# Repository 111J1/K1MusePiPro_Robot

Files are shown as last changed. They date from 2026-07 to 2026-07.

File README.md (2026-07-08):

# K1MUSE — 全链路本地具身智能服务机器人


[]()

> [!WARNING]
> ## ⚠️ 重要声明
>
> 本仓库是对真实部署代码的**重构版本**，用于展示**核心算法和系统架构设计**。
>
> **本仓库不能直接部署运行**，原因包括但不限于：
> - 缺少运行时依赖：SpacemiT AI SDK、sherpa-onnx 模型文件、ROS2 系统镜像、Orbbec 相机 SDK 等
> - 部分文件路径、IP 地址、网络配置已从真实部署环境中抽象化
> - 硬件相关文件（设备树、udev 规则、systemd 服务、SSH 密钥路径等）需根据实际硬件调整
> - AI 模型权重文件（唤醒词、ASR、YOLO、TTS 等）未包含在本仓库中
>
> 本仓库仅供**学习、参考和研究**使用。

---

## 项目简介

K1MUSE 是一台基于**进迭时空 K1 (SpacemiT K1) RISC-V 处理器**的全链路本地具身智能服务机器人。所有 AI 推理（语音识别、视觉检测、大语言模型、语音合成）均在边缘端完成，无需云端依赖。

**核心能力：** 语音交互 → 视觉感知 → LLM 理解 → 自主导航 → 机械臂操作

**硬件平台：**
- **主控**: SpacemiT K1 Muse Pi Pro (RISC-V 64-bit, ~2 TOPS NPU)
- **协处理**: STM32G474 (Cortex-M4F, 实时电机控制)
- **传感器**: LD06 激光雷达, YB IMU, Orbbec 深度相机
- **执行器**: 4 轮麦克纳姆底盘 + 可升降 6-DOF 机械臂 + 电动夹爪

## 系统架构

```mermaid
graph TB
    subgraph "Android 手机"
        APP[RobotController<br/>蓝牙遥控 / 地图 / 导航]
    end

    subgraph "K1 MusePi Pro - ROS2 Humble"
        AI[语音链路<br/>唤醒词→VAD→ASR→意图→TTS]
        VISION[视觉检测<br/>YOLO + 3D 定位]
        LLM[本地 LLM<br/>llama.cpp HTTP API]
        SUPERVISOR[多模态监督器<br/>8 状态交互 FSM]
        SLAM[SLAM 导航<br/>Cartographer + Nav2]
        BRIDGE_MCU[MCU 串口桥<br/>UART 帧协议]
        BRIDGE_BT[蓝牙 App 桥<br/>K1MB 协议]
        CONTROL[上层控制<br/>取放任务规划]
    end

    subgraph "STM32G474 - FreeRTOS"
        CHASSIS[4 轮麦克纳姆底盘<br/>PID 速度控制]
        ARM[SO101 5-DOF 机械臂<br/>IK 运动学]
        LIFT[升降机构<br/>PID 位置控制]
    end

    APP <--"蓝牙 RFCOMM<br/>(K1MB 协议)"--> BRIDGE_BT
    BRIDGE_BT --> SUPERVISOR
    AI --> SUPERVISOR
    VISION --> SUPERVISOR
    LLM --> AI
    SUPERVISOR --> CONTROL
    CONTROL --> BRIDGE_MCU
    SLAM --> BRIDGE_MCU
    BRIDGE_MCU <--"UART<br/>(0xA5 0x5A 帧)"--> CHASSIS
    BRIDGE_MCU <--"UART"--> ARM
    BRIDGE_MCU <--"UART"--> LIFT
```

## 仓库结构

```
k1muse/
├── firmware/          STM32G474 FreeRTOS 固件（底盘/机械臂/升降台）
├── ros2/              所有 ROS2 包
│   ├── navigation/    导航与通信（SLAM, MCU 桥, 蓝牙桥, LiDAR, IMU）
│   ├── ai/            AI 运行时（语音/视觉/LLM/多模态监督器）
│   └── control/       上层控制（取放任务, 抓取配置, STM32 串口客户端）
├── android/           Android 蓝牙遥控器（Kotlin/Jetpack Compose）
├── hardware/          硬件设计（3D CAD, PCB, MATLAB 运动学, URDF）
├── docs/              集中文档（架构, 协议, 快速入门）
└── tools/             开发工具脚本
```

## 快速导航

| 我想... | 查看 |
|---|---|
| 了解底盘控制算法 | [`firmware/Application/Module/mdl_chassis.c`](firmware/Application/Module/mdl_chassis.c) |
| 了解机械臂 IK 运动学 | [`firmware/Application/Module/SO101ARM/so101_algorithm.c`](firmware/Application/Module/SO101ARM/so101_algorithm.c) |
| 了解 AI 运行时架构 | [`ros2/ai/k1muse_ai_runtime/`](ros2/ai/k1muse_ai_runtime/) |
| 了解多模态交互 FSM | [`ros2/ai/k1muse_multimodal_supervisor/`](ros2/ai/k1muse_multimodal_supervisor/) |
| 了解语音意图路由 | [`ros2/ai/k1muse_voice_intent/`](ros2/ai/k1muse_voice_intent/) |
| 了解取放任务规划 | [`ros2/control/k1muse_control_core/`](ros2/control/k1muse_control_core/) |
| 了解通信协议 | [`docs/protocol.md`](docs/protocol.md) |
| 了解 Android App | [`android/`](android/) |
| 了解机械结构 | [`hardware/cad/`](hardware/cad/) |
| 了解 PCB 设计 | [`hardware/pcb/`](hardware/pcb/) |

## 关键技术指标

| 指标 | 数值 |
|---|---|
| AI 推理延迟（语音→意图） | < 2s（全本地） |
| SLAM 建图精度 | 0.05m 分辨率 |
| 机械臂重复定位精度 | ±1.5cm |
| 底盘最大速度 | 1.4 m/s |
| 升降行程 | 0.5m |
| 机械臂工作半径 | 0.5m |
| 蓝牙地图传输 | zlib 压缩分块, 最大 4MiB |

## 许可

- **软件代码** (`firmware/`, `ros2/`, `android/`, `tools/`): [Apache License 2.0](LICENSE)
- **硬件设计** (`hardware/`): [CC-BY-SA 4.0](hardware/README.md)
- **文档** (`docs/`): [CC-BY 4.0](docs/)

第三方代码（STM32 HAL, FreeRTOS, CMSIS, LDROBOT 激光雷达驱动等）保留其原始许可。

## 相关链接

- 进迭时空 K1: https://www.spacemit.com
- ROS2 Humble: https://docs.ros.org/en/humble/
- Cartographer: https://google-cartographer-ros.readthedocs.io/
- Nav2: https://navigation.ros.org/
- sherpa-onnx: https://github.com/k2-fsa/sherpa-onnx

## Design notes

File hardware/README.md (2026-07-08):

# 硬件设计文件

> [!WARNING]
> ## ⚠️ 重要声明
> 本目录包含的是设计参考文件，不构成可直接生产的完整制造包。
> 详见[仓库根目录 README](../README.md)。

## 许可

**CC-BY-SA 4.0** — 署名-相同方式共享 4.0 国际

您可以自由地：
- 分享 — 在任何媒介以任何形式复制、发行本作品
- 改编 — 修改、转换或以本作品为基础进行创作

惟须遵守下列条件：
- 署名 — 必须给出适当的署名
- 相同方式共享 — 如果您再混合、转换或者基于本作品进行创作，您必须基于与原先许可协议相同的许可协议分发您贡献的作品

完整许可文本: https://creativecommons.org/licenses/by-sa/4.0/legalcode.zh-hans

## 目录结构

```
hardware/
├── cad/         3D CAD 文件 (.step, .stl, .3mf)
│   ├── chassis/    底盘部件（麦克纳姆轮安装、电池支架等）
│   ├── arm/        SO101 5-DOF 机械臂零件
│   ├── lift/       升降机构（多层平台）
│   └── mounts/     传感器安装座（LiDAR、相机、红外等）
├── pcb/         PCB 设计文件（立创 EDA 格式）
│   ├── motor-driver/   电机驱动板
│   ├── stm32-core/     STM32G474 核心板
│   └── baseboard/      泰山派扩展底板
├── matlab/      MATLAB 运动学分析脚本
│   └── assets/         可视化用 STL 模型
└── urdf/        URDF 机器人描述文件
```

## 软件

- 3D CAD: Fusion 360 / SolidWorks (推荐)
- PCB: 立创 EDA
- MATLAB: R2023a+

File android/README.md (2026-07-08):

# Android 蓝牙控制器 App

> [!WARNING]
> ## ⚠️ 重要声明
> 本模块是对真实部署代码的重构版本，用于展示核心算法和系统架构。**不能直接部署运行。**
> 详见[仓库根目录 README](../README.md)。

## 概述

基于 Kotlin + Jetpack Compose 的 Android 机器人遥控器，通过经典蓝牙 (RFCOMM/SPP) 与机器人通信。

## 双模式

- **Direct SPP 模式**: 通过 HC-05 蓝牙模块直接控制 STM32 底盘 (只写)
- **K1 Map/Nav 模式**: 连接 K1 上位机，实时查看 SLAM 地图、机器人位姿、导航路径 (双向 K1MB 协议)

## 技术栈

| 项目 | 版本/值 |
|---|---|
| Kotlin | 2.2.10 |
| Compose BOM | 2026.02.01 |
| AGP | 9.2.1 |
| Min SDK | 28 |
| Target SDK | 36 |
| 包名 | com.embodiedai.robotcontroller |

## 关键特性

- 自定义 K1MB 二进制协议（17 种消息类型，最大 4 MiB 载荷）
- zlib 压缩地图分块渲染（ByteArray 环形缓冲区，避免 GC 卡顿）
- 4 种蓝牙连接 fallback 策略
- 监督器自动探测 → 启动 bridge → 5 次自动重连
- 地图多边形区域标注（最近自由栅格中心计算）
- 拖拽平移、双指缩放 (0.25x-16x)、0/90/180/270 度旋转

## 核心文件

| 文件 | 功能 |
|---|---|
| `K1MapModeScreen.kt` | 地图/Nav 主界面 (~3900 行) |
| `K1MobileProtocol.kt` | K1MB 协议编解码 + 帧解析器 |
| `ControlProtocol.kt` | STM32 Direct SPP 帧编码 |
| `K1MapBluetoothClient.kt` | 蓝牙连接 + 遥操线程 |
| `RegionModels.kt` | 地图区域数据模型 |

## 许可

Apache License 2.0

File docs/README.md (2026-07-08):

# 项目文档

## 文档索引

| 文档 | 内容 |
|---|---|
| `architecture.md` | 完整系统架构说明 |
| `protocol.md` | K1↔STM32 和 K1↔App 通信协议规范 |
| `INTERFACE.md` | 外部接口规范（原 MusePiPro_prj） |
| `ENV_DEV.md` | 部署环境恢复手册 |
| `SPECS.md` | 系统规格说明 |
| `CURRENT_RUNTIMEFLOW.md` | AI 运行时数据流 |
| `control_manager_api_contract.md` | 控制管理器 API 约定 |
| `control_manager_engineering_architecture.md` | 控制管理器工程架构 |
| `coordinate_frames_and_lift_z.md` | 坐标系与升降 Z 说明 |

## 许可

文档内容以 [CC-BY 4.0](https://creativecommons.org/licenses/by/4.0/) 许可发布。

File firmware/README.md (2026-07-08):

# STM32G474 固件 — 实时控制层

> [!WARNING]
> ## ⚠️ 重要声明
> 本模块是对真实部署代码的重构版本，用于展示核心算法和系统架构。**不能直接部署运行。**
> 详见[仓库根目录 README](../README.md)。

## 概述

基于 STM32G474VCT6 (Cortex-M4F, 144MHz) 的实时控制固件，运行 FreeRTOS V10.3.1。

## 架构

```
Application/
├── Algorithm/      CRC8, PID 控制器
├── Device/         硬件抽象层（电机、舵机、传感器、OLED）
├── Driver/         寄存器级驱动（HRTIM, UART DMA, ADC, I2C, DWT）
├── Module/         业务逻辑层
│   ├── SO101ARM/   SO101 5-DOF 机械臂 + 逆运动学
│   ├── mdl_chassis   麦克纳姆底盘运动学
│   ├── mdl_lift      升降机构 PID 控制
│   ├── mdl_control_protocol   二进制帧协议解析
│   └── mdl_control_arbitration  控制权仲裁
└── Task/           FreeRTOS 8 个任务入口
```

## FreeRTOS 任务拓扑

| 任务 | 优先级 | 周期 | 功能 |
|---|---|---|---|
| CommandTask | High (24) | 10ms | UART 帧解析与分发 |
| ChassisTask | AboveNormal (22) | 10ms | 底盘运动控制 |
| ArmTask | AboveNormal (22) | 10ms | 机械臂状态机 |
| LiftTask | AboveNormal (22) | 10ms | 升降台 PID + 归零 |
| TelemetryTask | Normal (20) | 事件驱动 | 遥测编码与发送 |
| PeripheralTask | Normal (20) | 周期 | 传感器轮询 |
| DemoTask | Normal (20) | 10ms | 演示序列编排 |
| OledTask | Low (18) | 100ms | OLED 显示 |

## 通信协议

与上位机 (K1) 通过 UART 通信，二进制帧格式：
`0xA5 0x5A SRC TARGET CMD SEQ LEN PAYLOAD(0-64) CRC8`

详见 [`docs/protocol.md`](../docs/protocol.md)。

## 关键算法

- **机械臂 IK**: 螺旋转轴 (PoE) 表示，位置用阻尼最小二乘法 (LM)，姿态用闭式解析解
- **底盘**: 麦克纳姆轮逆运动学 (4 轮)，1/√2 缩放，330 RPM 饱和保护
- **升降台**: P-only PID (Kp=7.0)，霍尔传感器归零 + 运行时参考修正

## 构建

- IDE: Keil MDK-ARM (Arm Compiler 6)
- STM32CubeMX 配置文件: `EmbodiedAI_Robot.ioc`

## 许可

Apache License 2.0

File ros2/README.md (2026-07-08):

# ROS2 包 — 上层计算层

> [!WARNING]
> ## ⚠️ 重要声明
> 本模块是对真实部署代码的重构版本，用于展示核心算法和系统架构。**不能直接部署运行。**
> 详见[仓库根目录 README](../README.md)。

## 概述

基于 ROS2 Humble 的上层计算软件栈，运行在 SpacemiT K1 MusePi Pro 上。分为三个子系统：

| 子系统 | 目录 | 功能 |
|---|---|---|
| 导航与通信 | [`navigation/`](navigation/) | SLAM 建图、路径规划、传感器驱动、通信桥 |
| AI 运行时 | [`ai/`](ai/) | 语音交互、视觉检测、LLM、多模态监督器 |
| 上层控制 | [`control/`](control/) | 取放任务规划、抓取配置、串口客户端 |

## 依赖关系

```
navigation/  ← 独立构建（LiDAR/IMU 驱动 + Cartographer + Nav2）
ai/          ← 依赖 control/（需先 source control 的 install）
control/     ← 独立构建（纯算法，无硬件依赖）
```

构建顺序：
```bash
# 1. 先构建 control
cd control/
colcon build

# 2. 再构建 ai（依赖 manager_msgs）
cd ai/
source ../control/install/setup.bash
colcon build

# 3. navigation 可以独立构建（但需要 LiDAR/IMU 硬件或 mock）
cd navigation/
colcon build
```

## 许可

Apache License 2.0

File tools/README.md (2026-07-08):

# 开发工具

> [!WARNING]
> ## ⚠️ 重要声明
> 本目录中的工具脚本是对真实部署版本的抽象。**可能需要根据实际环境调整路径和端口配置。**

## 工具列表

| 工具 | 功能 |
|---|---|
| `mcu_sim.py` | STM32 MCU 模拟器（通过 CH340 USB-UART），发送 ChassisStatus 帧并打印收到的命令 |
| `test_comms.py` | 通信测试脚本 |
| `full_chain_test.sh` | 全链路集成测试 |
| `demo_console.py` | 演示控制台（通过蓝牙发送演示命令） |
| `demo_tuning_profile.json` | 演示调试参数 |
| `bluetooth_pairing_agent.py` | BlueZ 自动配对代理 |

## 许可

Apache License 2.0

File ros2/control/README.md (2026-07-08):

# 上层控制子系统

> [!WARNING]
> ## ⚠️ 重要声明
> 本模块是对真实部署代码的重构版本。**不能直接部署。** 详见[仓库根目录 README](../../README.md)。

## 包含的 ROS2 包

| 包 | 语言 | 功能 |
|----|---|---|
| `k1muse_control_core` | C11 | 纯 C 库：串行帧协议、取放状态机 (22 状态)、放置规划器、抓取配置验证 |
| `k1muse_control_manager` | C++17 | ROS2 动作服务器：任务执行、抓取执行器、设备就绪管理、STM32 串口客户端 |
| `k1muse_task_manager` | C++17 | ROS2 节点：语音意图 → ExecuteTask 动作路由 |
| `k1muse_manager_msgs` | ROS2 IDL | 任务/动作消息定义 (ExecuteTask.action, TaskStatus.msg) |

## 取放任务流程

```
语音意图 → TaskManager → ExecuteTask Action → ControlManager
    → GraspTaskExecutor
        → stop_all()
        → ensure_arm_ready() / ensure_lift_ready()  [回零优化]
        → lift_move_z() → arm_gripper(open)
        → move_pose(pregrasp) → move_pose(grasp)
        → arm_gripper(close) → settle → carry
```

## 放置规划器

输入：目标在底盘坐标系中的 3D 位置 + 抓取配置
输出：底盘移动距离/方向、升降台 Z 目标、4 个手臂姿态 (grasp/pregrasp/lifted/retreat)

## 抓取配置

预标定 3 个物体 4 种抓取方式：
- bottle.side, box.side, box.top, umbrella.top

## Demo-Tolerant 模式

- 手臂姿态容差：±1.5cm
- 夹持器：无故障即假定成功
- 升降台：严格检查 ±2cm

## 许可

Apache License 2.0

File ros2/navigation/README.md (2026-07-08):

# 导航与通信子系统

> [!WARNING]
> ## ⚠️ 重要声明
> 本模块是对真实部署代码的重构版本。**不能直接部署。** 详见[仓库根目录 README](../../README.md)。

## 包含的 ROS2 包

| 包 | 语言 | 功能 |
|----|---|---|
| `k1muse_mcu_bridge` | C++17 | STM32 串口桥接节点（UART 帧协议、里程计发布、cmd_vel 路由） |
| `k1muse_mobile_bridge` | C++17 + Python | 蓝牙 App 桥接（K1MB 协议、地图分块/zlib、位姿发布） |
| `k1muse_slam_nav` | Python/Launch | Cartographer SLAM + Nav2 导航编排 |
| `k1muse_description` | URDF/Xacro | 机器人模型（X-omni 底盘 + SO101 机械臂） |
| `ldlidar_stl_ros2` | C++14 | LD06 激光雷达驱动 |
| `imu_ros2_device` | Python | YB IMU 驱动 |
| `k1muse_exploration` | Python | RRT/Frontier 自主探索 |

## 硬件接口

| 设备 | 端口 | 波特率 |
|---|---|---|
| STM32 MCU | /dev/mymcu (UART4) | 115200 |
| LD06 LiDAR | /dev/mylidar (UART5) | 230400 |
| YB IMU | /dev/myimu (CH340 USB) | 115200 |
| 蓝牙 | /dev/rfcomm0 | — |

## 分布式部署

支持 MUSE Pi Pro + Raspberry Pi 4B 双机 ROS2 通信：
- MUSE: 传感器驱动 + 通信桥（实时 I/O）
- RPi4: Cartographer + Nav2 + 探索（计算密集型）
- 通信: 有线以太网 CycloneDDS, ROS_DOMAIN_ID=42

## 许可

Apache License 2.0

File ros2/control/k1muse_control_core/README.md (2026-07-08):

# k1muse_control_core 纯C控制核心

`k1muse_control_core` 是一套与操作系统和ROS2解耦的纯C控制核心，同时服务于：

- PC阶段：由Python脚本暂时替代K1主控板，通过USB-UART控制真实STM32。
- K1阶段：由ROS2 C++节点直接链接本C库，复用协议、规划和任务状态机。

本库不包含Python、ROS2、串口设备名、线程或操作系统相关代码。因此从PC迁移到K1时，只需替换外层通信和ROS2接口，不需要重写核心控制流程。

## 分层结构

本库参考STM32下位机的分层方式组织：

| 层级 | 目录 | 职责 |
|---|---|---|
| Algorithm | `src/algorithm` | CRC8及通用数学算法 |
| Protocol | `src/protocol` | 字节流帧编码、解析、粘包和拆包处理 |
| Device | `src/device` | STM32命令构造，以及STATUS/RESULT解析 |
| Module | `src/module` | 抓取配置校验、底盘和升降布置计算 |
| Task | `src/task` | 抓取、携带、运输和放置状态机 |

平台外壳只需提供：

- 当前时间。
- 收到的串口字节。
- 配置数据。
- 命令完成、失败、超时或取消事件。
- 将C核心输出的动作发送给STM32。

PC平台外壳位于 `tools/pc_controller`；最终K1平台外壳将由ROS2 C++节点实现。

## 协议层

协议层实现STM32当前使用的帧格式：

```text
SOF1 SOF2 SRC TARGET CMD SEQ LEN PAYLOAD CRC8
```

当前目标编号以STM32源码为准：

```text
SYSTEM  = 0x00
CHASSIS = 0x01
ARM     = 0x02
LIFT    = 0x03
```

协议层支持：

- CRC-8/ATM。
- 最大64字节载荷。
- 小端整数和IEEE754浮点数。
- 半帧、连续多帧和错误CRC处理。
- ARM和LIFT命令RESULT解析。
- CHASSIS、ARM和LIFT周期STATUS解析。

协议常量应始终以STM32工程中的 `mdl_control_protocol.h` 为准，不应复制旧版上位机说明中的编号。

## 布置规划

规划器输入：

- 目标TCP在底盘坐标系中的位置。
- 机械臂相对底盘的安装参数。
- 升降范围。
- 物品抓取配置。

规划器输出：

- 底盘平移方向和距离。
- 升降目标高度。
- 最终抓取位姿。
- 预抓取位姿。
- 试提位姿。
- 抓取后的退出位姿。

当前第一版要求输入坐标已经位于底盘坐标系：X向前、Y向左、Z向上。

## 抓取和放置状态机

状态机采用事件驱动方式，不在C核心内部使用线程或阻塞等待：

```text
安全停止
→ 机械臂回安全位
→ 升降回零
→ 底盘移动到抓取位置
→ 升降移动到抓取高度
→ 打开夹爪
→ 移动到预抓取点
→ 移动到最终TCP
→ 固定角度闭合夹爪
→ 等待夹爪稳定
→ 小幅试提
→ 移动到携带姿态
→ 底盘运输
→ 升降移动到放置高度
→ 移动到预放置点
→ 移动到最终放置点
→ 打开夹爪
→ 等待释放
→ 机械臂退出
→ 完成
```

外部收到命令完成、失败、超时或取消事件后，再调用状态机推进到下一阶段。PC阶段由Python循环调用；K1阶段由ROS2回调或定时器调用。

## 安全设计

- 未标定的物品配置禁止真实执行。
- 任务失败、超时或取消时，状态机输出 `STOP_ALL`。
- `STOP_ALL`要求分别向底盘、升降和机械臂发送STOP。
- 底盘运动必须持续刷新MOV，避免超过STM32的300 ms控制超时。
- ARM和LIFT命令必须等待匹配SEQ的最终RESULT。
- 后一个机械臂命令必须等待前一个命令完成，避免触发 `SUPERSEDED`。

## 本地测试

纯C测试覆盖：

- CRC标准校验值。
- 协议帧编码和解析。
- 错误CRC拒绝。
- 抓取配置校验。
- 底盘与升降布置计算。
- 顶部抓取预抓取点计算。
- 完整抓取—运输—放置状态机。
- 超时后的安全停止。

## 在K1上构建

```bash
cd <workspace_root>
colcon build --packages-select k1muse_control_core
colcon test --packages-select k1muse_control_core
```

最终ROS2 C++节点可通过 `extern "C"` 直接包含本库头文件并链接该库。

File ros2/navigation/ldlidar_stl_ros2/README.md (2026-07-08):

# LDROBOT LD06 ROS2 Node

This package is trimmed for the LDROBOT LD06 LiDAR used by this project.

## Build

```bash
cd /home/bianbu/k1muse_slam_ros
source /opt/ros/humble/setup.bash
colcon build
source install/setup.bash
```

## Run

Start the LD06 node:

```bash
ros2 launch ldlidar_stl_ros2 ld06.launch.py
```

Start the LD06 node with RViz2:

```bash
ros2 launch ldlidar_stl_ros2 viewer_ld06.launch.py
```

## Serial Port

The project udev rule maps the LD06 serial adapter to `/dev/mylidar`.
The standalone launch file publishes `/scan` and uses this path:

```python
{'port_name': '/dev/mylidar'}
```

Install the project rule from
`/home/bianbu/k1muse_slam_ros/src/udev/99-ros2-slam.rules` on the board if
`/dev/mylidar` is missing.

## Integrated K1 Bringup

The main `k1muse_slam_nav _sensors.launch.py` does not expose raw LD06 data
directly as `/scan`. It starts this node on `/scan_raw`, then runs
`k1_scan_self_filter.py` to remove points inside the robot footprint and publish
the filtered scan as `/scan` for Cartographer and Nav2.

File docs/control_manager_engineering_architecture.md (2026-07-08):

# Control Manager Engineering Architecture

## Goal

Move the verified PC-side actuator behavior into the existing ROS2 `k1muse_control_manager` framework. Formal handoff should use the manager package, config, and pure C core; PC-side validation tools remain local bring-up and regression tooling in the full development workspace.

## Runtime Shape

```text
control_manager_node
  -> task dispatch
  -> GraspTaskExecutor
  -> DeviceSession
  -> Stm32ActuatorClient
  -> SerialTransport
  -> k1muse_control_core
  -> STM32 lower-computer
```

The default backend is `mock`. The real K1 deployment selects `backend: stm32_uart`.

## Formal Task Model

```text
pick       pick object and end at carry pose, still clamped
place      place currently held object, open gripper, retreat
pick_place pick followed by place
stop       STOP_ALL
lift       lift only
find       existing vision interaction
move/rotate reserved for navigation/chassis integration
```

Compatibility/debug:

```text
grasp   alias of pick
release manual gripper open only
```

`release` is not a formal place task.

## Device Session

Arm home is not repeated when the arm is already ready:

```text
has_fault == false
is_busy == false
state in {IDLE, WAIT_TARGET, REACHED}
```

This preserves the nearest-solution IK behavior during continuous tasks.

Lift home is skipped after it has been homed once and has no fault:

```text
has_fault == false
is_homed == true
```

If lift has fault:

```text
LIFT_CLEAR_FAULT
LIFT_HOME
```

## Pick Flow

```text
STOP_ALL
ENSURE_ARM_READY
ENSURE_LIFT_READY
LIFT_MOVE_Z
GRIPPER_OPEN
PREGRASP
GRASP
GRIPPER_CLOSE
WAIT_SETTLE
CARRY
DONE_HOLDING
```

Pick never releases the object.

## Place Flow

Place is derived from the same pickup profile. No independent place profile is introduced in the first engineering version.

Reverse mapping:

```text
place_pose    = pickup.grasp_pose
approach_pose = pickup.lifted_pose
preplace_pose = pickup.retreat_pose
retreat_pose  = pickup.retreat_pose
lift_target_z = pickup.lift_target_z for the place target_z
```

Flow:

```text
STOP_ALL
ENSURE_ARM_READY
ENSURE_LIFT_READY
LIFT_MOVE_Z
PREPLACE
APPROACH
PLACE
GRIPPER_OPEN
WAIT_SETTLE
RETREAT
CARRY
DONE_RELEASED
```

## Config

Formal config:

```text
k1muse_control_manager/config/control_manager.real.yaml
k1muse_control_manager/config/grasp_profiles.yaml
```

Calibrated objects:

```text
bottle.side
box.side
box.top
umbrella.top
```

The pitch value for top grasps remains `1.5`, not `1.57`.

## Safety

Cancel and exceptions call:

```text
STOP_ALL
```

`demo_tolerant` mode keeps the validated competition-video behavior:

```text
gripper timeout without arm fault -> assumed success
arm pose failure with xyz_error <= 0.015 m -> assumed success
lift fault -> explicit failure, then clear+home before next lift move
```

`strict` mode requires matching completed results.

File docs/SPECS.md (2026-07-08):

# V1 Current System Specs

Last rebuilt: 2026-06-26

This is the source-backed V1 system specification. It describes what exists in the current repository and whether it is part of the V1 runtime chain.

## Current Stage

- Development stage: Windows-first static development and no-hardware validation.
- Primary V1 target: stable mock voice/vision/manager loop plus K1 board-port preparation.
- Primary mock launch: `k1muse_manager_ros/src/k1muse_robot_bringup/launch/robot.mock.launch.py`.
- Primary board preparation launch: `k1muse_manager_ros/src/k1muse_robot_bringup/launch/robot.real_k1.launch.py`.
- Full board deployment: not completed as a whole-system claim. Intent hardening was user-confirmed on board on 2026-06-26; other hardware paths still need their own smoke evidence.
- Current real audio config fact: `plughw:2,0` for both capture and playback in `k1muse_core_ros/src/k1muse_voice_audio/config/audio_io.real_k1.yaml`.
- Excluded from current V1 facts: `k1muse_slam_ros/**`, `k1muse_communicate_ros/src/k1muse_mcu_bridge/**`, OCR/RapidOCR integration, and full K1 deployment.

## V1 Intent Hardening Summary

Current status: completed for the V1 intent-hardening scope, with board/runtime success confirmed by the user on 2026-06-26.

| Item | Current fact | Evidence | Status |
|---|---|---|---|
| Intent node | `intent_node` consumes `/voice/listen/result` and publishes `/voice/intent`, `/voice/tts/text`, `/voice/intent/status`, and `/intent/state`. | `k1muse_voice_intent/src/intent_node.cpp` | Implemented |
| Fast intent layer | Deterministic stop, simple motion, lift, query/chat, find, reminder list/create extraction and empty-reminder protection. | `src/fast_intent.cpp`, `include/k1muse_voice_intent/fast_intent.hpp` | Implemented |
| Route policy | Fast candidates carry category, slot state and reject reason; long/complex relative motion is guarded before task execution. | `src/intent_router.cpp`, `include/k1muse_voice_intent/intent_router.hpp` | Implemented |
| LLM mapping | LLM output is still the flat four-field contract: `kind`, `direction`, `target`, `reply`; `lift` maps to `action=lift,target=lift`. | `src/llm_intent_mapper.cpp`, `src/llm_response_validator.cpp` | Implemented |
| Structured output | Code supports `response_format=none|json_object|json_schema`; current board usage is `json_object` according to user confirmation. | `src/llama_server_client.cpp`, `src/intent_node.cpp`, user-confirmed runtime fact | Implemented with `json_object`; `json_schema` future stabilization |
| Runtime observability | Intent logs include `route_source`, `fast_category`, `fast_slot`, `fast_reject_reason`, `llm_status`, `response_format`, final intent/action/target/value and latency. | `src/intent_node.cpp` | Implemented |

Design boundary: the LLM output intentionally stays simple and fast. Complex behavior should be derived by local post-processing in `IntentRouter`, `LlmIntentMapper`, task/reminder managers, or future V2 policy code rather than by asking the model to emit a nested JSON plan.

## Workspace Overview

| Module | Path | Current role | V1 runtime chain? | Evidence | Status |
|---|---|---|---|---|---|
| Core ROS workspace | `k1muse_core_ros/src` | Audio, voice, AI runtime, supervisor, vision, mock devices, core messages. | Yes | package directories and CMake files under `k1muse_core_ros/src/**` | Active |
| Manager ROS workspace | `k1muse_manager_ros/src` | Task manager, control manager, manager messages, bringup launch/config. | Yes | `k1muse_robot_bringup/launch/*.launch.py`, manager packages | Active |
| Communicate workspace | `k1muse_communicate_ros` | Future MCU bridge area. | No | only referenced by `robot.real_motion.launch.py` comments as external requirement | Future |
| SLAM workspace | `k1muse_slam_ros` | Future SLAM/Nav area. | No | not referenced by V1 main launch | Future |
| External SDK material | `AI_SDK` | Board SDK/model/tooling material. | Dependency only | referenced by CMake and board config paths, not a ROS package boundary | External |
| Python contract tests | `test` | Static/contract checks that do not require ROS2 runtime. | Test support | `test/test_interface_contracts.py`, `test/test_v2_architecture_contracts.py` | Keep |
| Manual board/test scripts | `run_test` | Manual pipeline/audio scripts and sample audio. | No launch reference | `run_test/README.md`, `run_one_round.sh`, `test_pipeline.sh`, audio WAVs | Keep as dev support |
| Scratch output | `tmp` | Duplicate scripts and doc scan facts. | No | `tmp/doc_rebuild_scan/**`, duplicate `run_test` scripts | Scratch |
| Developer tooling | `tools` | Board log helper. | Support only | `tools/k1logs.ps1` | Keep |

## Package Inventory

| Package | Path | Current role | V1 runtime chain? | Evidence | Status |
|---|---|---|---|---|---|
| `k1muse_common` | `k1muse_core_ros/src/k1muse_common` | Shared QoS helpers and `NodeReady.msg`. | Yes | `msg/NodeReady.msg`, `include/k1muse_common/qos_profiles.hpp` | Implemented |
| `k1muse_audio_msgs` | `k1muse_core_ros/src/k1muse_audio_msgs` | Audio frame interface. | Yes | `msg/AudioFrame.msg` | Implemented |
| `k1muse_voice_msgs` | `k1muse_core_ros/src/k1muse_voice_msgs` | Wake/listen/intent/TTS/audio playback messages. | Yes | `msg/WakewordEvent.msg`, `msg/ListenResult.msg`, `msg/IntentLite.msg`, `msg/TtsTextRequest.msg`, `msg/TtsPlayRequest.msg`, `msg/AudioPlaybackState.msg` | Implemented |
| `k1muse_voice_audio` | `k1muse_core_ros/src/k1muse_voice_audio` | Unified audio capture and playback lifecycle node. | Yes | `src/audio_io_node.cpp`, `config/audio.mock.yaml`, `config/audio_io.real_k1.yaml` | Partial: mock path exists; ALSA board validation pending |
| `k1muse_voice_intent` | `k1muse_core_ros/src/k1muse_voice_intent` | ASR text to structured intent plus TTS reply, with hardened FastIntent/LLM routing. | Yes | `src/intent_node.cpp`, `src/intent_router.cpp`, `src/fast_intent.cpp`, `src/llama_server_client.cpp`, `config/intent.real_k1.yaml` | Implemented for V1 intent hardening; current board mode uses `json_object` by user confirmation |
| `k1muse_voice_reminder` | `k1muse_core_ros/src/k1muse_voice_reminder` | Reminder intent handling and TTS request publishing. | Yes | `src/reminder_node.cpp`, `config/reminder.mock.yaml` | Implemented for V1 scope |
| `k1muse_ai_runtime_msgs` | `k1muse_core_ros/src/k1muse_ai_runtime_msgs` | Runtime state/control/mode/resource/alert/pose interfaces. | Interfaces yes; some are V2 reserved | `msg/AiRuntimeControl.msg`, `msg/AiRuntimeState.msg`, `msg/AiruntimeMode.msg`, `msg/Pose2DFrame.msg`, services | Mixed: current and V2-reserved interfaces |
| `k1muse_ai_runtime` | `k1muse_core_ros/src/k1muse_ai_runtime` | Lifecycle inference runtime for wake/VAD/ASR/vision/TTS scheduling. | Yes | `src/ai_runtime_node.cpp`, `src/runtime_scheduler.cpp`, `src/resource_guard.cpp`, `config/ai_runtime.mock.yaml`, `config/ai_runtime.real_k1.yaml` | Partial: V1 mock path and V2 skeleton exist; real K1 validation pending |
| `k1muse_multimodal_supervisor` | `k1muse_core_ros/src/k1muse_multimodal_supervisor` | Interaction state owner and runtime control publisher. | Yes | `src/multimodal_supervisor_node.cpp`, `src/interaction_state_machine.cpp`, `config/supervisor.mock.yaml` | Implemented for V1 control loop |
| `k1muse_vision_msgs` | `k1muse_core_ros/src/k1muse_vision_msgs` | 2D detection, target request/response, target 3D messages. | Yes | `msg/Detection2DFrame.msg`, `msg/TargetRequest.msg`, `msg/TargetResponse.msg`, `msg/Target3D.msg` | Implemented |
| `k1muse_vision_3d` | `k1muse_core_ros/src/k1muse_vision_3d` | Converts selected 2D detection plus registered depth and color camera info into `Target3D`. | Yes, but partial | `src/vision_3d_node.cpp`, `config/vision_3d.mock.yaml` | Partial: code topics and config root aligned; board camera runtime verification pending |
| `k1muse_mock_devices` | `k1muse_core_ros/src/k1muse_mock_devices` | Deterministic mock audio, RGB camera, depth camera publishers. | Yes in mock launch only | `audio_scenario_node`, `camera_scenario_node`, `depth_camera_scenario_node` in CMake and launch | Keep as mock/test |
| `k1muse_manager_msgs` | `k1muse_manager_ros/src/k1muse_manager_msgs` | Manager task/motion/status interfaces. | Yes | `action/ExecuteTask.action`, `action/ExecuteMotion.action`, `srv/StopAndLatch.srv`, `msg/TaskStatus.msg` | Implemented |
| `k1muse_task_manager` | `k1muse_manager_ros/src/k1muse_task_manager` | Routes `IntentLite` to task/motion action goals and stop/reset services. | Yes | `src/task_manager_node.cpp`, `config/task_manager.mock.yaml`, `config/task_manager.real.yaml` | Partial: mock path primary |
| `k1muse_control_manager` | `k1muse_manager_ros/src/k1muse_control_manager` | Hosts task/motion action servers, target request flow, optional motion executor. | Yes | `src/control_manager_node.cpp`, `src/relative_motion_executor.cpp`, `config/control_manager.mock.yaml`, `config/control_manager.real.yaml` | Partial: real motion disabled in V1 main launch |
| `k1muse_robot_bringup` | `k1muse_manager_ros/src/k1muse_robot_bringup` | Launch/config entry package. | Yes | `launch/robot.mock.launch.py`, `launch/robot.real_k1.launch.py` | Implemented, with real-motion launch risk |

## Current Executables And Nodes

| Executable | Runtime node name | Package | Launch evidence | Main source | Status |
|---|---|---|---|---|---|
| `ai_runtime_node` | `ai_runtime` | `k1muse_ai_runtime` | `ai_runtime.mock.launch.py`, `ai_runtime.real_k1.launch.py` | `src/main.cpp`, `src/ai_runtime_node.cpp` | Lifecycle node |
| `audio_io_node` | `audio_io` | `k1muse_voice_audio` | `robot.mock.launch.py`, `robot.real_k1.launch.py` | `src/main.cpp`, `src/audio_io_node.cpp` | Lifecycle node |
| `intent_node` | `intent_node` | `k1muse_voice_intent` | `robot.mock.launch.py`, `robot.real_k1.launch.py` | `src/main.cpp`, `src/intent_node.cpp` | Regular node |
| `supervisor_node` | `multimodal_supervisor` | `k1muse_multimodal_supervisor` | `robot.mock.launch.py`, `robot.real_k1.launch.py` | `src/main.cpp`, `src/multimodal_supervisor_node.cpp` | Regular node |
| `task_manager_node` | `task_manager` | `k1muse_task_manager` | `robot.mock.launch.py`, `robot.real_k1.launch.py` | `src/main.cpp`, `src/task_manager_node.cpp` | Regular node |
| `control_manager_node` | `control_manager` | `k1muse_control_manager` | `robot.mock.launch.py`, `robot.real_k1.launch.py` | `src/main.cpp`, `src/control_manager_node.cpp` | Regular node |
| `reminder_node` | `reminder_node` | `k1muse_voice_reminder` | `robot.mock.launch.py`, `robot.real_k1.launch.py` | `src/main.cpp`, `src/reminder_node.cpp` | Regular node |
| `vision_3d_node` | launch name `vision_3d`, internal constructor `vision_3d_node` | `k1muse_vision_3d` | `robot.mock.launch.py`, `targeting.mock.launch.py` | `src/main.cpp`, `src/vision_3d_node.cpp` | Regular node; YAML root now matches launch name `vision_3d` |
| `audio_scenario_node` | `audio_scenario` | `k1muse_mock_devices` | `robot.mock.launch.py`, `voice_flow.mock.launch.py` | `src/audio_scenario_main.cpp` | Mock only |
| `camera_scenario_node` | `camera_scenario` | `k1muse_mock_devices` | `robot.mock.launch.py`, `targeting.mock.launch.py` | `src/camera_scenario_node.cpp` | Mock only |
| `depth_camera_scenario_node` | `depth_camera_scenario` | `k1muse_mock_devices` | `robot.mock.launch.py`, `targeting.mock.launch.py` | `src/depth_camera_scenario_node.cpp` | Mock only |

## Interface Inventory

| Package | Interfaces | Current role |
|---|---|---|
| `k1muse_common` | `msg/NodeReady.msg` | Readiness from `audio_io` and `intent_node` to supervisor. |
| `k1muse_audio_msgs` | `msg/AudioFrame.msg` | `/audio/raw_pcm` payload. |
| `k1muse_voice_msgs` | `WakewordEvent`, `ListenEvent`, `ListenResult`, `IntentStatus`, `IntentLite`, `TtsTextRequest`, `TtsStatus`, `TtsPlayRequest`, `AudioPlayRequest`, `AudioPlaybackState` | Voice pipeline topics. |
| `k1muse_vision_msgs` | `Detection2D`, `Detection2DFrame`, `TargetRequest`, `TargetResponse`, `Target3D` | Vision detection and find/target flow. |
| `k1muse_ai_runtime_msgs` | `AiRuntimeControl`, `AiRuntimeState`, `AiruntimeMode`, `AiruntimeResource`, `AiruntimeAlert`, `Pose2D`, `Pose2DFrame`, `SetMode`, `GetMode`, `EnableDetector` | Current runtime state/control plus V2 mode/alert/pose reservations. |
| `k1muse_manager_msgs` | `TaskStatus`, `MotionState`, `InteractionState`, `ExecuteTask.action`, `ExecuteMotion.action`, `StopAndLatch.srv`, `ResetMotionLatch.srv` | Manager action/status/control interfaces. |

## Launch Entry Inventory

| Launch file | Purpose | Included nodes/configs | Status |
|---|---|---|---|
| `k1muse_robot_bringup/launch/robot.mock.launch.py` | Primary V1 mock launch. | Includes `ai_runtime.mock.launch.py`; starts audio, intent, supervisor, task/control manager, reminder, vision_3d, and mock devices. | Primary V1 entry |
| `k1muse_robot_bringup/launch/voice_flow.mock.launch.py` | Smaller voice-flow mock. | Includes AI runtime, `audio_io`, `intent_node`, supervisor, `audio_scenario_node`. | Dev/test support |
| `k1muse_robot_bringup/launch/targeting.mock.launch.py` | Smaller vision/targeting mock. | Includes AI runtime, supervisor, `vision_3d`, RGB/depth mock devices. | Dev/test support |
| `k1muse_robot_bringup/launch/robot.real_k1.launch.py` | Board no-motion preparation. | Includes `ai_runtime.real_k1.launch.py`, ALSA `audio_io`, real intent config, real supervisor config, mock/no-motion managers, reminder, vision_3d. | Board preparation, not proof |
| `k1muse_robot_bringup/launch/robot.real_motion.launch.py` | Future real motion experiment. | Includes `robot.mock.launch.py`, then starts another control manager and task manager with real configs. | Not V1 mainline; must be redesigned before use |
| `k1muse_ai_runtime/launch/ai_runtime.mock.launch.py` | Standalone mock AI runtime lifecycle launch. | `ai_runtime_node` with `ai_runtime.mock.yaml`; autostart configure/activate. | Implemented |
| `k1muse_ai_runtime/launch/ai_runtime.real_k1.launch.py` | Standalone real K1 AI runtime lifecycle launch. | `ai_runtime_node` with `ai_runtime.real_k1.yaml`; autostart configure/activate. | Board preparation |

## Config Inventory

| Config | Used by | Important facts | Status |
|---|---|---|---|
| `k1muse_ai_runtime/config/ai_runtime.mock.yaml` | `ai_runtime.mock.launch.py` | `backend_mode: mock`, mock ASR/detection/TTS values, provider parameters. | Current mock |
| `k1muse_ai_runtime/config/ai_runtime.real_k1.yaml` | `ai_runtime.real_k1.launch.py` | `backend_mode: real`, sherpa KWS path, SenseVoice path, YOLO path, Matcha TTS path, 60s job deadline. | Board prep |
| `k1muse_ai_runtime/config/profiles.yaml` | V2 profile candidate | NORMAL/GUARD/PATROL/VOICE_ONLY/STANDBY schedules. | V2 design/config, not fully V1 behavior |
| `k1muse_ai_runtime/config/detectors.yaml` | V2 detector candidate | yolov8n, pose, fire detector records; `backend: mock` currently. | V2 design/config |
| `k1muse_voice_audio/config/audio.mock.yaml` | `robot.mock.launch.py` | wildcard root, `device_type: mock`. | Current mock |
| `k1muse_voice_audio/config/audio_io.real_k1.yaml` | `robot.real_k1.launch.py` | `device_type: alsa`, `capture_device: plughw:2,0`, `playback_device: plughw:2,0`. | Board prep |
| `k1muse_voice_intent/config/intent.mock.yaml` | `robot.mock.launch.py` | fast intent enabled, LLM fallback enabled, route policy parameters and structured-output params defaulted off. | Current mock |
| `k1muse_voice_intent/config/intent.real_k1.yaml` | `robot.real_k1.launch.py` | `llm_backend: real`, API base `http://127.0.0.1:8080/v1`, deterministic sampling, route policy parameters, and structured-output params. Current board runtime uses `json_object` by user confirmation; future target is `json_schema`. | Board intent path implemented; whole-system board deployment still separate |
| `k1muse_voice_intent/config/llama_server.real_k1.yaml` | No current parser in `intent_node`; comment says intent node does not parse it. | llama-server process proposal. | Manual/board support only |
| `k1muse_multimodal_supervisor/config/supervisor.mock.yaml` | mock launch | `no_speech_timeout_sec`, `wake_ack_preset`, `target_cache_ttl_ms`. | Current |
| `k1muse_multimodal_supervisor/config/supervisor.real_k1.yaml` | real K1 launch | same key parameters as mock. | Board prep |
| `k1muse_vision_3d/config/vision_3d.mock.yaml` | mock and real K1 launches | YAML root is `vision_3d`, matching launch name `vision_3d`. | Static alignment done; runtime param dump still useful on ROS2 |
| `k1muse_control_manager/config/control_manager.mock.yaml` | mock and no-motion real launch | `mock_delay_ms`, `find_timeout_ms`; no motion enabled. | Current V1 |
| `k1muse_control_manager/config/control_manager.real.yaml` | real motion experiment | `motion_enabled: true`, speed limits, control rate. | Future/experimental |
| `k1muse_task_manager/config/task_manager.mock.yaml` | mock and real K1 no-motion launch | `default_timeout_ms: 5000`. | Current V1 |
| `k1muse_task_manager/config/task_manager.real.yaml` | real motion experiment | distance/angle bounds. | Future/experimental |
| `k1muse_voice_reminder/config/reminder.mock.yaml` | mock and real K1 launch | timezone, timer, SQLite path. | Current V1 |
| `k1muse_robot_bringup/config/robot.mock.yaml`, `robot.real_k1.yaml` | no inspected launch reads these | mode/no_motion metadata. | Low-value unless wired |

## External Dependencies

| Dependency | Current code evidence | Is it called by V1 runtime? | Status |
|---|---|---|---|
| SpacemiT AI SDK | `k1muse_ai_runtime/CMakeLists.txt` fixed paths `/home/bianbu/AI_SDK/ai-sdk`; real backend sources. | Only when real backends are built and launched on board. | Board dependency |
| sherpa-onnx | `real_sherpa_wakeword_backend.cpp`, `ai_runtime.real_k1.yaml` KWS paths. | Only real wakeword backend. | Board dependency |
| SenseVoice | `real_sensevoice_asr_backend.cpp`, `sensevoice_asr_model_path`. | Only real ASR backend. | Board dependency |
| llama-server | `intent_node.cpp`, `llama_server_client.cpp`, `intent.real_k1.yaml`. | Real intent path when compiled and server is available; supports OpenAI-compatible `response_format=json_object|json_schema`. Current board runtime uses `json_object` by user confirmation. | Board/external process |
| PortAudio | `k1muse_voice_audio/CMakeLists.txt`, `portaudio_backend.cpp`. | Possible audio backend; current real K1 YAML uses ALSA. | Optional |
| ALSA | `alsa_backend.cpp`, `audio_io.real_k1.yaml`. | Yes for K1 real audio config. | Board dependency |
| RapidOCR | current maintained source search found no V1 ROS2 call path. | No. | External/future only |

## Feature Status Matrix

| Area | Current code evidence | Status | Notes |
|---|---|---|---|
| Mock voice loop | `audio_scenario_node -> /audio/raw_pcm -> ai_runtime -> intent_node -> supervisor -> ai_runtime/audio_io` | Implemented/partial | Source and launch exist; runtime execution still requires ROS2 environment. |
| Real audio capture/playback | `audio_io.real_k1.yaml`, `audio_io_node.cpp`, `alsa_backend.cpp` | Partial | Uses `plughw:2,0`; board device and permissions not proven here. |
| Wake/VAD/ASR/TTS runtime | `WakewordRuntime`, `VadAsrRuntime`, `TTSRuntime`, `BackendFactory` | Partial | Mock path present; real backends depend on SDK/model paths. |
| Intent parsing | `fast_intent.cpp`, `intent_router.cpp`, `llm_intent_mapper.cpp`, `llm_response_validator.cpp`, `llama_server_client.cpp`, `intent_node.cpp` | Implemented for V1 intent hardening | Fast/LLM route policy, safe fallback, flat JSON object output and current `json_object` structured output are in place; `json_schema` remains future stabilization. |
| Supervisor state/control | `multimodal_supervisor_node.cpp`, `interaction_state_machine.cpp`, `runtime_control_builder.cpp` | Implemented | Publishes `/ai_runtime/control` and `/robot/interaction_state`. |
| Mock RGB vision input | `camera_scenario_node.cpp` publishes `/camera/main/color/image_raw`; `ai_runtime_node.cpp` subscribes `/camera/main/color/image_raw` | Partial | Static topic wiring is aligned; ROS2 runtime smoke still required. |
| 2D detection output | `ai_runtime_node.cpp` publishes `/vision/detection_2d` | Partial | RGB input topic is aligned; actual detection output still depends on runtime backend/model behavior. |
| 3D target flow | `vision_3d_node.cpp`, `TargetRequest/Response/Target3D` | Partial | Code subscribes `/camera/main/depth_registered/image_raw` and `/camera/main/color/camera_info`; runtime frame/timestamp validation remains. |
| Manager ExecuteTask | `task_manager_node.cpp`, `control_manager_node.cpp`, `ExecuteTask.action` | Implemented for mock | Real semantics need hardening. |
| Real motion | `ExecuteMotion.action`, `relative_motion_executor.cpp`, `control_manager.real.yaml` | Future/partial | Not part of V1 main launch. |
| V2 runtime modes | `profiles.yaml`, `RuntimeProfileManager`, `AiruntimeMode.msg` | Design/skeleton | Not current V1 behavior unless explicitly wired. |
| V2 pose/fire alert | `MockPoseBackend`, `MockFireBackend`, `AiruntimeAlert.msg`, `AlertEventPublisher` | Design/skeleton | No separate `k1muse_vision_alert` package. |
| SLAM/Nav2 | `k1muse_slam_ros/**` | Not V1 | No V1 main launch inclusion. |
| MCU bridge | `k1muse_communicate_ros/src/k1muse_mcu_bridge/**` | Not V1 | Only future real-motion comment reference. |
| OCR/RapidOCR | external material only | Not implemented | Current code found no ROS2 integration. |
| Full board deployment | board configs and launch exist | Not complete | Needs hardware smoke records. |

## Known Corrections

- Old docs that said current audio device is `plughw:1,0` are outdated. Current config says `plughw:2,0`.
- Old docs that include `slam`, `mcubridge`, OCR, or full board deployment as current V1 runtime are outdated unless revalidated.
- `AudioIoNode` currently owns both capture and playback paths, not playback only.
- `AiruntimeMode`, `AiruntimeAlert`, `Pose2D`, `Pose2DFrame`, `SetMode`, `GetMode`, and `EnableDetector` existing as interfaces does not prove V2 runtime behavior is active.

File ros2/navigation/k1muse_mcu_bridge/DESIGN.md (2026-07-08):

# MCU 桥接节点设计方案

## 目录结构

```
k1muse_communicate_ros/src/
    ├── udev/
    │   ├── 99-ros2-communicate.rules       # ttyS4 → /dev/mymcu
    │   └── README.md
    └── k1muse_mcu_bridge/
        ├── CMakeLists.txt
        ├── package.xml
        ├── msg/                        # 自定义 ROS 消息
        │   ├── ChassisStatus.msg       # 上行：底盘状态（32B 原样）
        │   └── ChassisMov.msg          # 下行：底盘 MOV 命令（13B 原样）
        ├── srv/                        # 自定义 ROS 服务
        │   ├── ChassisStop.srv         # 空请求
        │   └── ChassisOdom.srv         # direction, x, y
        ├── include/k1muse_mcu_bridge/
        │   ├── cmd_vel_router.hpp      # /cmd_vel 到 chassis MOV/STOP 的可选路由
        │   ├── odom_publisher.hpp      # /odom 和 odom -> base_footprint
        │   ├── protocol.hpp            # 帧格式、CRC8、全部枚举（含 arm/lift）
        │   ├── serial_port.hpp         # 串口操作封装
        │   └── mcu_bridge_node.hpp     # 节点主类
        ├── scripts/
        │   ├── k1_start_mcu_bridge.sh
        │   └── k1_stop_mcu_bridge.sh
        └── src/
            ├── cmd_vel_router.cpp
            ├── odom_publisher.cpp
            ├── protocol.cpp
            ├── serial_port.cpp
            └── mcu_bridge_node.cpp
```

---

## 一、udev 规则

`99-ros2-communicate.rules`：

```
KERNEL=="ttyS4", MODE:="0777", SYMLINK+="mymcu"
```

波特率 115200 8N1 由节点代码设置。

---

## 二、协议常量（protocol.hpp）

与 STM32 端 `mdl_control_protocol.h` 保持一致。**枚举定义全部目标模块**，即使本阶段只实现 chassis，代码层面已预留给 arm/lift 的解析入口。

```cpp
// 帧格式
constexpr uint8_t SOF1 = 0xA5;
constexpr uint8_t SOF2 = 0x5A;
constexpr uint8_t MAX_PAYLOAD = 64;
constexpr uint8_t HEADER_SIZE = 7;
constexpr uint8_t MAX_FRAME = HEADER_SIZE + MAX_PAYLOAD + 1;  // 72

// 源标识
enum class Src : uint8_t {
    NONE = 0x00,
    BT   = 0x01,
    HOST = 0x02,    // 本节点固定使用
    MCU  = 0x10,
};

// 模块（全部定义，方便后续扩展）
enum class Target : uint8_t {
    SYSTEM  = 0x00,
    CHASSIS = 0x01,
    ARM     = 0x02,
    LIFT    = 0x03,
};

// 底盘命令
enum class ChassisCmd : uint8_t {
    STOP = 0x00,
    MOV  = 0x01,
    ODOM = 0x02,
};

// 状态帧命令号
constexpr uint8_t STATUS_CMD = 0x80;
```

**扩展时**：在此文件追加 `ArmCmd`、`LiftCmd` 枚举即可。

---

## 三、ROS 接口（本阶段：仅 chassis）

### 3.1 上行 Topic（MCU → ROS）

| Topic | 消息 | Payload |
|---|---|---|
| `/mcu/chassis/status` | `ChassisStatus.msg` | 32B |
| `/odom` | `nav_msgs/Odometry` | 由 chassis status 同生命周期换算发布 |
| `odom -> base_footprint` | TF | 默认发布，可由 `publish_tf` 控制 |

**ChassisStatus.msg**（与 MCU `ctrl_chassis_status_payload_t` 一致）：
```
uint32 tick_ms
uint8  state
uint8  move_cs
uint8  motor_block_flags
uint8  reserved
float32 wcs_vx
float32 wcs_vy
float32 omega
float32 wcs_x
float32 wcs_y
float32 wcs_direction
```

**扩展 arm/lift 时**：新增 `ArmStatus.msg`、`LiftStatus.msg`，在 `CMakeLists.txt` 的 `rosidl_generate_interfaces` 中追加，节点中新增 publisher。

### 3.2 下行 Topic（ROS → MCU）

| Topic | 消息 | 说明 |
|---|---|---|
| `/mcu/chassis/mov` | 自定义消息 | 下行 MOV 帧 |
| `/cmd_vel` | `geometry_msgs/Twist` | 可选订阅，`enable_cmd_vel_output=true` 时路由到 `/mcu/chassis/mov` 或 `/mcu/chassis/stop` |

`msg/ChassisMov.msg`（与 MCU `ctrl_chassis_mov_payload_t` 一致）：
```
uint8  move_cs     # 0=LCS, 1=WCS
float32 direction
float32 v
float32 omega
```

### 3.3 下行 Service

| Service | 请求字段 | 响应 |
|---|---|---|
| `/mcu/chassis/stop` | 空 | 空 |
| `/mcu/chassis/odom` | `float32 direction`, `float32 x`, `float32 y` | 空 |

**扩展 arm/lift 时**：新增对应的 `.srv` 文件和 service server，模式完全一致。

---

## 四、节点架构

**单节点，双线程。**

```
┌──────────────────────────────────────────────────────────┐
│                   mcu_bridge_node                         │
│                                                           │
│  ┌──────────────┐          ┌────────────────────────────┐ │
│  │  ReadThread   │──发布──→│  /mcu/chassis/status        │ │
│  │               │         │  (后续 + /mcu/arm/status    │ │
│  │  字节流→SOF   │         │        + /mcu/lift/status)  │ │
│  │  →CRC8→反序列│         └────────────────────────────┘ │
│  │  →TARGET分发  │                                        │
│  └──────┬───────┘                                        │
│         │                                                │
│     /dev/mymcu                                           │
│         │                                                │
│  ┌──────┴───────┐          ┌────────────────────────────┐ │
│  │  主线程       │←─────────│  /mcu/chassis/mov (Topic)   │ │
│  │              │←─────────│  /mcu/chassis/stop (Service) │ │
│  │  SEQ→组帧   │←─────────│  /mcu/chassis/odom (Service) │ │
│  │  →CRC8→写   │          │  (后续 + arm/*, lift/*)      │ │
│  └──────────────┘          └────────────────────────────┘ │
└──────────────────────────────────────────────────────────┘
```

### 读线程

```
loop:
  read bytes from serial port → append to buffer
  while buffer has complete frame:
    find 0xA5 0x5A
    read SRC + TARGET + CMD + SEQ + LEN (5 bytes)
    read LEN bytes payload
    read 1 byte CRC
    if CRC8 mismatch: discard, skip 1 byte, continue

    if SRC == MCU (0x10) && CMD == STATUS_CMD (0x80):
      switch TARGET:
        CHASSIS → deserialize → publish /mcu/chassis/status
        ARM     → (预留，暂不处理)
        LIFT    → (预留，暂不处理)
    else:
      // 非状态帧（如 BT 中继），暂忽略
```

**扩展 arm/lift 时**：在 switch 的 ARM/LIFT 分支中分别 deserialize + publish。

### 主线程

**Subscriber `/mcu/chassis/mov`**：
```
callback(msg):
  payload = serialize(msg)   // 13 bytes
  frame = build(Target::CHASSIS, ChassisCmd::MOV, seq++, payload)
  write(frame)
```

**Service `/mcu/chassis/stop`**：
```
callback(req, resp):
  frame = build(Target::CHASSIS, ChassisCmd::STOP, seq++, empty)
  write(frame)
  return resp
```

**Service `/mcu/chassis/odom`**：
```
callback(req, resp):
  payload = serialize(req.direction, req.x, req.y)  // 12 bytes
  frame = build(Target::CHASSIS, ChassisCmd::ODOM, seq++, payload)
  write(frame)
  return resp
```

**build 函数**（通用）：
```
输入: target, cmd, seq, payload
输出: [SOF1, SOF2, SRC_HOST, target, cmd, seq, len, payload..., crc8]
```

**扩展 arm/lift 时**：新增 subscriber/service callback，调用同一个 `build()`，仅 target/cmd/payload 不同。

---

## 五、关键细节

| 项目 | 决策 |
|---|---|
| **SRC** | 固定 0x02（HOST） |
| **SEQ** | 节点内部自增 uint8_t，溢出回绕 |
| **CRC8** | ATM 多项式 0x07，初始 0x00，覆盖 SRC~PAYLOAD |
| **字节序** | 全小端，float32 用 `memcpy` |
| **串口读** | 非阻塞，缓冲区 ≥ 256 字节 |
| **串口写** | 加锁保护，避免读写线程竞争 |
| **重连** | 串口异常 → 1s 间隔重试，恢复后继续 |
| **CRC 失败** | 丢弃帧，跳过 1 字节重新搜 SOF |

---

## 六、扩展模式

以新增 arm 为例，后续只需三步：

1. **定义接口**：新增 `msg/ArmStatus.msg`、`srv/ArmStop.srv`、`srv/ArmMoveXyz.srv` 等
2. **CMakeLists.txt**：`rosidl_generate_interfaces` 追加新文件
3. **节点代码**：各约 5 行
   - 成员变量加一个 `rclcpp::Publisher<ArmStatus>::SharedPtr`
   - 构造函数加 `create_publisher` + `create_service` 调用
   - 读线程 switch 的 ARM 分支加 deserialize + publish
   - 主线程加 service callback

无需改动 `protocol.hpp`（枚举已预定义）、`serial_port`、`build()` 等公共逻辑。

---

## 七、里程计和 `/cmd_vel` 路由

`mcu_bridge_node` 现在把桥接、里程计发布和速度路由放在同一个生命周期内，避免多个节点同时依赖底盘状态。

### `/odom` 发布

默认参数：

| 参数 | 默认值 | 含义 |
|---|---:|---|
| `odom_frame` | `odom` | 里程计父坐标系 |
| `base_frame` | `base_footprint` | 车体投影坐标系 |
| `publish_tf` | `true` | 是否发布 `odom -> base_footprint` |
| `odom_publish_rate_hz` | `50.0` | 发布频率 |

`/odom` 来自 `/mcu/chassis/status` 中的 `wcs_x`、`wcs_y`、`wcs_direction`、`wcs_vx`、`wcs_vy`、`omega`。协方差使用温和 2D 数值，避免 RViz 因极大协方差显示异常。

### `/cmd_vel` 路由

默认参数：

| 参数 | 默认值 | 含义 |
|---|---:|---|
| `enable_cmd_vel_output` | `false` | 默认只读，不向 MCU 发 MOV/STOP |
| `vx_limit` | `1.4` | `linear.x` 限幅 |
| `vy_limit` | `1.4` | `linear.y` 限幅 |
| `omega_limit` | `3.7` | `angular.z` 限幅 |
| `cmd_vel_timeout_ms` | `250` | 超时后发零速/STOP |
| `cmd_vel_rate_hz` | `20` | MOV 重发频率 |
| `zero_vel_send_stop` | `true` | 全零速度调用 `/mcu/chassis/stop` |

只读建图或排查时保持默认：

```bash
ros2 run k1muse_mcu_bridge mcu_bridge_node
```

App 手动控制或 Nav2 控车时显式开启：

```bash
ros2 run k1muse_mcu_bridge mcu_bridge_node --ros-args -p enable_cmd_vel_output:=true
```

安装脚本 `k1_start_mcu_bridge.sh` 当前会先确认 `/dev/mymcu` 有数据，再以 `enable_cmd_vel_output:=true` 启动节点；`k1_stop_mcu_bridge.sh` 停止前会尝试发布一次零 `/cmd_vel`。

---

## 八、依赖

**package.xml**：
- `rclcpp`
- `geometry_msgs`
- `nav_msgs`
- `tf2`
- `tf2_ros`
- `rosidl_default_generators` / `rosidl_default_runtime`

**CMakeLists.txt**：
- `find_package(rclcpp REQUIRED)`
- `find_package(geometry_msgs REQUIRED)`
- `find_package(nav_msgs REQUIRED)`
- `find_package(tf2 REQUIRED)`
- `find_package(tf2_ros REQUIRED)`
- `rosidl_generate_interfaces(...)` 生成 msg/srv
- 可执行文件 `mcu_bridge_node`

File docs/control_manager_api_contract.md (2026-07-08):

# Control Manager API Contract

## Action Entry

The formal upper-computer entry remains:

```text
k1muse_manager_msgs/action/ExecuteTask
```

The control manager owns actuator execution only. Vision, speech, and task policy should provide a resolved object, variant, and target height.

## Formal Task Types

```text
find
pick
place
pick_place
stop
lift
move
rotate
```

Compatibility/debug task types:

```text
grasp    alias of pick
release  debug/manual gripper-open only
```

`release` is not the formal place task. A formal place task must include lift, arm approach, gripper open, settle, and retreat.

## Goal Fields

```text
string task_type
string target_class
string target_id
float32 target_z
float32 place_z
bool hold
builtin_interfaces/Duration timeout
```

Field semantics:

```text
target_class  bottle / box / umbrella
target_id     side / top, empty means default variant
target_z      pick TCP height for pick; place TCP height for place
place_z       place TCP height for pick_place
hold          legacy field; pick always ends holding at carry pose
timeout       whole-task timeout
```

## Pick Contract

Input example:

```text
task_type = "pick"
target_class = "umbrella"
target_id = "top"
target_z = 0.350
```

Behavior:

```text
STOP_ALL
ENSURE_ARM_READY
ENSURE_LIFT_READY
LIFT_MOVE_Z
GRIPPER_OPEN
ARM_MOVE_PREGRASP
ARM_MOVE_GRASP
GRIPPER_CLOSE
WAIT_SETTLE
ARM_MOVE_CARRY
DONE_HOLDING
```

Important: pick ends at carry pose while keeping the object clamped. It must not release.

## Place Contract

Input example:

```text
task_type = "place"
target_class = "umbrella"
target_id = "top"
target_z = 0.350
```

Place planning must be derived from the same pick profile. No independent place parameters are introduced in the first engineering version.

Reverse mapping:

```text
place_pose    = pickup.grasp_pose
approach_pose = pickup.lifted_pose
preplace_pose = pickup.retreat_pose
retreat_pose  = pickup.retreat_pose
lift_target_z = pickup.lift_target_z for the place target_z
```

Behavior:

```text
STOP_ALL
ENSURE_ARM_READY
ENSURE_LIFT_READY
LIFT_MOVE_Z
ARM_MOVE_PREPLACE
ARM_MOVE_APPROACH
ARM_MOVE_PLACE
GRIPPER_OPEN
WAIT_SETTLE
ARM_MOVE_RETREAT
ARM_MOVE_CARRY
DONE_RELEASED
```

## Pick-Place Contract

Input example:

```text
task_type = "pick_place"
target_class = "umbrella"
target_id = "top"
target_z = 0.350
place_z = 0.450
```

Behavior:

```text
pick(target_z)
place(place_z)
```

`place_z` is required for `pick_place`. This avoids overloading one height field with two physical meanings.

## Stop Contract

```text
task_type = "stop"
```

Behavior:

```text
STOP chassis
STOP lift
STOP arm
```

STOP must be valid in any state and should release lower-computer arbitration.

## Lift Contract

```text
task_type = "lift"
target_class = absolute lift z in meters
```

Behavior:

```text
ENSURE_LIFT_READY
LIFT_MOVE_Z
```

If lift has a fault:

```text
LIFT_CLEAR_FAULT
LIFT_HOME
LIFT_MOVE_Z
```

## Result Semantics

Success:

```text
success = true
final_state = 2
reason = "completed"
```

Failure:

```text
success = false
final_state = 3
reason = concrete error text
```

Cancel:

```text
success = false
final_state = 4
reason = "Task cancelled"
```

## Execution Policy

`demo_tolerant`:

```text
gripper timeout without arm fault -> success with warning
arm pose timeout/failed with xyz_error <= 0.015 m -> success with warning
lift fault -> fail current command, recover through clear + home before next movement
```

`strict`:

```text
only matching COMPLETED RESULT is success
```

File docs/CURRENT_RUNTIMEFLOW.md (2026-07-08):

# Current V1 Runtime Flow

Last rebuilt: 2026-06-26

This document traces the current V1 runtime from launch files and node source. It separates current code facts from old design and future plans.

## Primary V1 Entry

The primary current V1 entry is:

```bash
ros2 launch k1muse_robot_bringup robot.mock.launch.py
```

Evidence: `k1muse_manager_ros/src/k1muse_robot_bringup/launch/robot.mock.launch.py`.

The primary board preparation entry is:

```bash
ros2 launch k1muse_robot_bringup robot.real_k1.launch.py
```

Evidence: `k1muse_manager_ros/src/k1muse_robot_bringup/launch/robot.real_k1.launch.py`.

`robot.real_motion.launch.py` is not a V1 main entry. It includes `robot.mock.launch.py` and then starts additional manager nodes with real configs, so it can duplicate `task_manager` and `control_manager` processes. It also comments that `k1muse_communicate_ros` and `k1muse_slam_ros` are required separately.

## Launch Loading Order

`robot.mock.launch.py` returns a `LaunchDescription` in this order:

1. Declares `autostart`.
2. Includes `k1muse_ai_runtime/launch/ai_runtime.mock.launch.py`.
3. Starts lifecycle `audio_io`.
4. Registers configure/activate events for `audio_io`.
5. Starts `intent_node`.
6. Starts `multimodal_supervisor`.
7. Starts `task_manager`.
8. Starts `control_manager`.
9. Starts `reminder_node`.
10. Starts `vision_3d`.
11. Starts `audio_scenario_node`.
12. Starts `camera_scenario_node`.
13. Starts `depth_camera_scenario_node`.

`ai_runtime.mock.launch.py` starts lifecycle `ai_runtime` and autostarts configure and activate.

Important: launch order is not proof that every topic path is connected. Topic names still need to match node source.

## V1 Mock Runtime Diagram

```mermaid
flowchart TD
  A["audio_scenario_node<br/>k1muse_mock_devices<br/>/audio/raw_pcm"] --> B["ai_runtime<br/>k1muse_ai_runtime<br/>WakewordRuntime/VadAsrRuntime"]
  B --> C["/ai_runtime/wakeword/event<br/>/ai_runtime/listen/event<br/>/voice/listen/result"]
  C --> D["intent_node<br/>k1muse_voice_intent"]
  D --> E["/voice/intent<br/>/voice/tts/text<br/>/voice/intent/status"]
  E --> F["multimodal_supervisor<br/>k1muse_multimodal_supervisor"]
  F --> G["/ai_runtime/control<br/>/voice/audio/play<br/>/robot/interaction_state"]
  E --> H["task_manager<br/>k1muse_task_manager"]
  H --> I["execute_task / execute_motion<br/>action clients"]
  I --> J["control_manager<br/>k1muse_control_manager"]
  J --> K["/vision/target_request"]
  K --> F
  F --> L["/vision/target_response"]
  L --> M["vision_3d<br/>k1muse_vision_3d"]
  M --> N["/vision/main/target_3d"]
  N --> J
  D --> O["/voice/tts/text"]
  O --> B
  B --> P["/voice/tts/play"]
  P --> Q["audio_io<br/>k1muse_voice_audio"]
  Q --> R["/voice/audio/playback_state<br/>/audio_io/state"]
  R --> F
  S["camera_scenario_node<br/>/camera/main/color/image_raw"] --> T["ai_runtime<br/>/camera/main/color/image_raw"]
  U["depth_camera_scenario_node<br/>/camera/main/depth_registered/image_raw"] --> M
  V["camera_scenario_node<br/>/camera/main/color/camera_info"] --> M
```

Camera edges above reflect the current code contract after topic alignment. The real camera package is external to this workspace, so board runtime validation is still required.

## Detailed Step Table

| Step | Node/package | Input | Output | Key config | Code evidence | Status |
|---|---|---|---|---|---|---|
| 1 | `ai_runtime` / `k1muse_ai_runtime` | lifecycle configure/activate | `/ai_runtime/state`, runtime publishers/subscribers | `config/ai_runtime.mock.yaml` | `launch/ai_runtime.mock.launch.py`, `src/ai_runtime_node.cpp::on_configure` | Implemented |
| 2 | `audio_io` / `k1muse_voice_audio` | lifecycle configure/activate | `/audio_io/state`, `/audio/raw_pcm`, `/voice/audio/playback_state` | `config/audio.mock.yaml` or `config/audio_io.real_k1.yaml` | `src/audio_io_node.cpp::on_configure`, `::on_activate` | Implemented/partial |
| 3 | `audio_scenario_node` / `k1muse_mock_devices` | timer | `/audio/raw_pcm` | inline launch params `scenario`, `publish_rate_ms` | `src/audio_scenario_main.cpp` | Mock only |
| 4 | `ai_runtime` voice input | `/audio/raw_pcm` | wake/listen/result topics | `wakeword_*`, VAD/ASR params in `ai_runtime.*.yaml` | `src/ai_runtime_node.cpp::on_audio_frame`, `WakewordRuntime`, `VadAsrRuntime` | Implemented/partial |
| 5 | `intent_node` / `k1muse_voice_intent` | `/voice/listen/result` | `/voice/intent`, `/voice/tts/text`, `/voice/intent/status`, `/intent/state` | `intent.mock.yaml` or `intent.real_k1.yaml` | `src/intent_node.cpp::on_listen_result`, `::process_intent`; `src/intent_router.cpp`; `src/fast_intent.cpp`; `src/llama_server_client.cpp` | Implemented for V1 intent hardening; current board structured output uses `json_object` by user confirmation |
| 6 | `multimodal_supervisor` | runtime, wake/listen, intent, TTS, audio, target topics | `/ai_runtime/control`, `/voice/audio/play`, `/vision/target_response`, `/robot/interaction_state` | `supervisor.mock.yaml` | `src/multimodal_supervisor_node.cpp` subscriptions and publishers | Implemented |
| 7 | `ai_runtime` TTS | `/voice/tts/text` | `/voice/tts/status`, `/voice/tts/play` | TTS provider/model params | `src/ai_runtime_node.cpp::on_tts_text_request`, `TTSRuntime` | Implemented/partial |
| 8 | `audio_io` playback | `/voice/tts/play`, `/voice/audio/play` | `/voice/audio/playback_state` | playback config/preset | `src/audio_io_node.cpp::on_tts_request`, `::on_audio_request`, `::worker_loop` | Implemented/partial |
| 9 | `task_manager` | `/voice/intent` | `execute_task`, `execute_motion`, stop/reset service clients, `/manager/task_status` | `task_manager.mock.yaml` | `src/task_manager_node.cpp::on_intent` | Partial |
| 10 | `control_manager` | `execute_task`, `execute_motion`, stop/reset services, target response/3D | `/vision/target_request`, `/cmd_vel`, `/control/motion_state` | `control_manager.mock.yaml` or `control_manager.real.yaml` | `src/control_manager_node.cpp`, `relative_motion_executor.cpp` | Mock in V1; real motion future |
| 11 | `camera_scenario_node` | timer | `/camera/main/color/image_raw`, `/camera/main/color/camera_info` | defaults in source | `src/camera_scenario_node.cpp` | Mock RGB/info source aligned with runtime topics |
| 12 | `ai_runtime` vision input | `/camera/main/color/image_raw` | `/vision/detection_2d` | `vision_provider`, model params | `src/ai_runtime_node.cpp::on_image_frame`, publisher around `/vision/detection_2d` | Topic aligned; backend/model runtime still partial |
| 13 | `depth_camera_scenario_node` | timer | `/camera/main/depth_registered/image_raw`, extra `/camera/main/depth_registered/camera_info` | defaults in source | `src/depth_camera_scenario_node.cpp` | Mock; current `vision_3d` consumes color camera_info instead |
| 14 | `vision_3d` | `/vision/detection_2d`, `/camera/main/depth_registered/image_raw`, `/camera/main/color/camera_info`, `/vision/target_response` | `/vision/main/target_3d` | `vision_3d.mock.yaml` | `src/vision_3d_node.cpp` | Topic/config aligned; runtime timestamp/depth validation pending |
| 15 | `reminder_node` | `/voice/intent` | `/voice/tts/text` | `reminder.mock.yaml` | `src/reminder_node.cpp` | Implemented for V1 |

## Voice Chain

Mock audio input:

```text
k1muse_mock_devices/audio_scenario_node
  publishes /audio/raw_pcm
  -> ai_runtime subscribes /audio/raw_pcm
```

Evidence:

- publisher: `k1muse_core_ros/src/k1muse_mock_devices/src/audio_scenario_main.cpp`
- subscriber: `k1muse_core_ros/src/k1muse_ai_runtime/src/ai_runtime_node.cpp`
- interface: `k1muse_core_ros/src/k1muse_audio_msgs/msg/AudioFrame.msg`

`ai_runtime` creates and uses:

- `WakewordRuntime`: `include/k1muse_ai_runtime/models/wakeword_runtime.hpp`, `src/models/wakeword_runtime.cpp`
- `VadAsrRuntime`: `include/k1muse_ai_runtime/models/vad_asr_runtime.hpp`, `src/models/vad_asr_runtime.cpp`
- backend selection: `src/backend_factory.cpp`
- scheduling: `RuntimeScheduler`, `ResourceGuard`, `BoundedCpuWorker`

Outputs:

- `/ai_runtime/wakeword/event`: `k1muse_voice_msgs/msg/WakewordEvent.msg`
- `/ai_runtime/listen/event`: `k1muse_voice_msgs/msg/ListenEvent.msg`
- `/voice/listen/result`: `k1muse_voice_msgs/msg/ListenResult.msg`
- `/ai_runtime/state`: `k1muse_ai_runtime_msgs/msg/AiRuntimeState.msg`

Intent and TTS relation:

```text
/voice/listen/result
  -> intent_node
    -> fast intent or LLM client
    -> /voice/intent
    -> /voice/tts/text
  -> ai_runtime
    -> TTSRuntime
    -> /voice/tts/status
    -> /voice/tts/play
  -> audio_io
    -> playback backend
    -> /voice/audio/playback_state
```

Current hardened intent behavior:

1. `intent_node` receives `ListenResult` and starts a traced request with `trace_id`, `request_id`, `utterance_id`, `epoch`, text length and LLM mode.
2. `IntentRouter` cleans ASR text and asks `MatchFastIntentCandidate` for a deterministic candidate.
3. Fast candidates carry `FastIntentCategory`, `SlotState` and route reason. Safety stop, clear short action, query/chat and valid extractive find/reminder paths can publish without LLM.
4. Complex or ambiguous input can call the real LLM client. Current board runtime uses OpenAI-compatible `response_format=json_object` according to user confirmation; code also supports `json_schema` for future stabilization.
5. LLM output remains intentionally flat: `{"kind":"","direction":"","target":"","reply":""}`. `LlmResponseValidator` validates the four-field object and `LlmIntentMapper` converts it into `IntentDecision`.
6. Unsafe or incomplete results are contained by router fallback. Examples: bare `提醒我` becomes ask-repeat; `lift` maps to `action=lift,target=lift`; long destination-like movement is not blindly sent as a relative move.
7. Runtime logs include `route_source`, `fast_category`, `fast_slot`, `fast_reject_reason`, `llm_status`, `response_format`, intent/action/target/value and request latency.

Evidence:

- Fast and route policy: `k1muse_core_ros/src/k1muse_voice_intent/src/fast_intent.cpp`, `src/intent_router.cpp`.
- LLM validation/mapping: `src/llm_response_validator.cpp`, `src/llm_intent_mapper.cpp`.
- Structured output support: `src/llama_server_client.cpp`, `include/k1muse_voice_intent/llama_server_client.hpp`.
- Runtime logs and ROS params: `src/intent_node.cpp`, `config/intent.real_k1.yaml`.
- Current `json_object` usage: user-confirmed board runtime fact on 2026-06-26.
Real LLM status:

- `intent.real_k1.yaml` sets `llm_backend: "real"` and `llm_api_base: "http://127.0.0.1:8080/v1"`; it also carries route-policy and structured-output parameters.
- `k1muse_voice_intent/CMakeLists.txt` has `K1MUSE_ENABLE_REAL_LLM_CLIENT` default ON and compiles `llama_server_client.cpp` when enabled.
- `llama_server.real_k1.yaml` says `intent_node` does not parse it. Treat it as board process support, not current node config evidence. Current board structured-output mode is `json_object` by user confirmation; switching to `json_schema` is a future stability/latency tradeoff task.

## Vision Chain

Current source topics:

```text
camera_scenario_node
  publishes /camera/main/color/image_raw
  publishes /camera/main/color/camera_info

ai_runtime
  subscribes /camera/main/color/image_raw
  publishes   /vision/detection_2d

depth_camera_scenario_node
  publishes /camera/main/depth_registered/image_raw
  publishes /camera/main/depth_registered/camera_info

vision_3d
  subscribes /vision/detection_2d
  subscribes /camera/main/depth_registered/image_raw
  subscribes /camera/main/color/camera_info
  subscribes /vision/target_response
  publishes  /vision/main/target_3d
```

Evidence:

- mock RGB: `k1muse_core_ros/src/k1muse_mock_devices/src/camera_scenario_node.cpp`
- AI runtime image subscription: `k1muse_core_ros/src/k1muse_ai_runtime/src/ai_runtime_node.cpp`
- mock depth: `k1muse_core_ros/src/k1muse_mock_devices/src/depth_camera_scenario_node.cpp`
- 3D node: `k1muse_core_ros/src/k1muse_vision_3d/src/vision_3d_node.cpp`

Current limitation:

- The static topic contract is now aligned to the user-confirmed real camera topics: `/camera/main/color/image_raw`, `/camera/main/depth_registered/image_raw`, `/camera/main/color/camera_info`.
- `camera_scenario_node` is a mock publisher in `k1muse_mock_devices`, not the real camera package.
- `depth_camera_scenario_node` still publishes an extra `/camera/main/depth_registered/camera_info` as mock-only legacy output; current `vision_3d` consumes `/camera/main/color/camera_info`.
- The real camera package lives outside this workspace; board smoke must still confirm publishers, QoS, timestamps, and frame IDs.

## AI Runtime Internals

Current `AiRuntimeNode::on_configure` loads runtime config, creates subscribers/publishers, creates model runtimes, creates `RuntimeCore`, loads models, and prepares lifecycle state.

Current V1 path:

- `WakewordRuntime`
- `VadAsrRuntime`
- `VisionRuntime` retained as V1 compatibility path
- `TTSRuntime`
- `RuntimeScheduler`
- `ResourceGuard`
- `BoundedCpuWorker`

V2 skeleton already exists but is not complete V1 behavior:

- `RuntimeCore`
- `VisionPipeline`
- `DetectorRegistry`
- `VisionDetectorScheduler`
- `VoiceExclusiveGuard`
- `RuntimeProfileManager`
- `AlertEventPublisher`
- `MockPoseBackend`
- `MockFireBackend`
- `profiles.yaml`
- `detectors.yaml`

Evidence: `k1muse_core_ros/src/k1muse_ai_runtime/src/ai_runtime_node.cpp`, `include/k1muse_ai_runtime/**`, and related test contracts.

## Supervisor And Manager Relationship

`multimodal_supervisor` is the current interaction-state owner:

- subscribes runtime/voice/audio/vision readiness and result topics
- publishes `/ai_runtime/control`
- publishes `/voice/audio/play`
- publishes `/vision/target_response`
- publishes `/robot/interaction_state`

Evidence: `k1muse_core_ros/src/k1muse_multimodal_supervisor/src/multimodal_supervisor_node.cpp`.

`task_manager` routes `IntentLite` to manager actions/services:

- subscribes `/voice/intent`
- action client `execute_task`
- action client `execute_motion`
- service clients `stop_and_latch`, `reset_latch`
- publishes `/manager/task_status`

Evidence: `k1muse_manager_ros/src/k1muse_task_manager/src/task_manager_node.cpp`.

`control_manager` hosts the action/service side:

- action server `execute_task`
- action server `execute_motion`
- services `stop_and_latch`, `reset_latch`
- publishes `/vision/target_request`
- subscribes `/vision/target_response`, `/vision/main/target_3d`
- optionally creates `RelativeMotionExecutor` when `motion_enabled` is true

Evidence: `k1muse_manager_ros/src/k1muse_control_manager/src/control_manager_node.cpp`, `src/relative_motion_executor.cpp`.

V1 main launches use mock/no-motion manager config. Real motion is a future board task.

## Real Audio Device Fact

`audio_io.real_k1.yaml` currently states:

```yaml
device_type: "alsa"
capture_device: "plughw:2,0"
playback_device: "plughw:2,0"
capture_sample_rate: 16000
capture_channels: 1
capture_frame_ms: 20
```

`robot.real_k1.launch.py` uses this file for `audio_io`. This is config evidence, not hardware proof. Board validation still requires `arecord`, `aplay`, ROS topic checks, and runtime logs.

## Current, Old, Future Boundary

| Item | Status | Why |
|---|---|---|
| `robot.mock.launch.py` chain | Current V1 | Starts maintained packages and mock devices. |
| `robot.real_k1.launch.py` no-motion board chain | Board preparation | Uses real configs but no stored board smoke evidence. |
| `robot.real_motion.launch.py` | Future/unsafe as V1 mainline | Includes mock launch and duplicates manager nodes. |
| SLAM/Nav2 | Future | No V1 main launch inclusion. |
| MCU bridge | Future | Only mentioned as external requirement in real-motion launch comments. |
| OCR/RapidOCR | Future/not implemented | Current ROS2 source search found no V1 integration. |
| V2 Pose/Fire mode system | Future/skeleton | Interfaces and classes exist; full pipeline and packages are not integrated as V1 behavior. |

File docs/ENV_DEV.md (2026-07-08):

# MUSE Pi Pro 完整部署手册

目标：从刷机后的空白板卡开始，按本文逐步操作，恢复到可 SSH、可构建、可运行双机分布式 ROS2 SLAM/Nav/探索的完整状态。本文也适用于更换树莓派或重新部署计算端。

## 约定

| 项目 | 值 |
|---|---|
| 本机仓库 | `E:\Embed_Game\MusePiPro_prj` |
| MUSE 板端用户 | `bianbu` |
| MUSE 板端 IP（Wi-Fi 管理） | `192.168.137.194` |
| MUSE 板端 IP（有线 ROS2） | `10.10.10.2/24` |
| MUSE SSH 别名 | `musepi` |
| MUSE 通信工作区 | `/home/bianbu/k1muse_communicate_ros` |
| MUSE SLAM 工作区 | `/home/bianbu/k1muse_slam_ros` |
| 树莓派计算端用户 | `user` |
| 树莓派有线 IP（ROS2） | `10.10.10.1/24` |
| 树莓派通信工作区 | `/home/user/k1muse_communicate_ros` |
| 树莓派 SLAM 工作区 | `/home/user/k1muse_slam_ros` |
| 树莓派 MPPI overlay | `/home/user/mppi_overlay` |
| ROS_DOMAIN_ID | `42` |
| RMW | `rmw_cyclonedds_cpp` |
| MUSE 内核 | `6.6.63` |
| SSH 密钥 | `C:\Users\YJY\.ssh\codex_musepi_ed25519` |

---

## 第一部分：单板 MUSE Pi Pro 部署

### 0. 本机准备

确认 SSH key 和别名：

```powershell
Test-Path C:\Users\YJY\.ssh\codex_musepi_ed25519
Get-Content C:\Users\YJY\.ssh\config
ssh musepi "hostname && uname -a"
```

`C:\Users\YJY\.ssh\config` 需要包含：

```sshconfig
Host musepi
    HostName 192.168.137.194
    User bianbu
    IdentityFile C:\Users\YJY\.ssh\codex_musepi_ed25519
    IdentitiesOnly yes
```

首次刷机后如果还不能免密，先用板端密码登录一次，把公钥写入板端：

```powershell
$pub = Get-Content C:\Users\YJY\.ssh\codex_musepi_ed25519.pub
ssh bianbu@192.168.137.194 "mkdir -p ~/.ssh && chmod 700 ~/.ssh && grep -qxF '$pub' ~/.ssh/authorized_keys 2>/dev/null || echo '$pub' >> ~/.ssh/authorized_keys; chmod 600 ~/.ssh/authorized_keys"
```

当前公钥：

```text
ssh-ed25519 AAAAC3NzaC1lZDI1NTE5AAAAIGwzSsLZgUuQaBi/0wqCRBoPCPdN1axxRAnCjR6djP9f codex-musepi
```

本机 Python 工具依赖：

```powershell
python -m pip install pyserial
```

### 1. 板端基础包

```bash
sudo apt-get update
sudo apt-get install -y \
  build-essential cmake git pkg-config \
  python3-pip python3-colcon-common-extensions \
  python3-serial python3-smbus2 \
  device-tree-compiler \
  openssh-server \
  wayvnc
```

ROS2 Humble 依赖：

```bash
sudo apt-get install -y \
  ros-humble-ament-cmake \
  ros-humble-rclcpp ros-humble-rclpy \
  ros-humble-rosidl-default-generators ros-humble-rosidl-default-runtime \
  ros-humble-sensor-msgs ros-humble-std-msgs \
  ros-humble-nav-msgs ros-humble-geometry-msgs \
  ros-humble-tf2 ros-humble-tf2-ros ros-humble-tf2-tools \
  ros-humble-launch ros-humble-launch-ros ros-humble-ros2launch \
  ros-humble-xacro ros-humble-urdf ros-humble-robot-state-publisher \
  ros-humble-cartographer ros-humble-cartographer-ros ros-humble-cartographer-rviz \
  ros-humble-slam-toolbox \
  ros-humble-rviz2 ros-humble-rviz-imu-plugin \
  ros-humble-rmw-cyclonedds-cpp
```

> MUSE 上不需要 `ros-humble-navigation2` 和 `ros-humble-nav2-*`，Nav2 只在树莓派上运行。

Python 包兜底：

```bash
python3 -m pip install --user pyserial smbus2
```

确认 ROS setup 路径：

```bash
ls -l /opt/ros/humble/setup.bash /opt/bros/humble/setup.bash 2>/dev/null || true
```

本文默认使用 `/opt/ros/humble/setup.bash`。如果当前镜像只提供 `/opt/bros/humble/setup.bash`，后续命令中的 `/opt/ros/humble/setup.bash` 改为 `/opt/bros/humble/setup.bash`。

### 2. 用户环境

`.bashrc` 至少需要 ROS2 环境：

```bash
grep -nE 'ROS|RMW|QT_QPA_PLATFORM|k1muse' ~/.bashrc || true
cat >> ~/.bashrc <<'EOF'

# K1 MUSE Pi Pro ROS2 environment
source /opt/ros/humble/setup.bash
export RMW_IMPLEMENTATION=rmw_cyclonedds_cpp
export QT_QPA_PLATFORM=xcb
EOF
```

有本机镜像时，优先用镜像恢复，但先确认文件存在并备份板端当前文件：

```powershell
cd E:\Embed_Game\MusePiPro_prj
Test-Path environment/.bashrc
ssh musepi "cp /home/bianbu/.bashrc /home/bianbu/.bashrc.pre-sync"
scp environment/.bashrc musepi:/home/bianbu/.bashrc
ssh musepi "bash -n /home/bianbu/.bashrc"
```

### 3. WayVNC 桌面

配置 LXQt Wayland 自动登录：

```bash
sudo mkdir -p /etc/sddm.conf.d
sudo tee /etc/sddm.conf.d/autologin.conf >/dev/null <<'EOF'
[Autologin]
User=bianbu
Session=lxqt-wayland.desktop
EOF
```

有本机镜像时恢复 `/home/bianbu/start_wayvnc.sh`：

```powershell
cd E:\Embed_Game\MusePiPro_prj
Test-Path environment/start_wayvnc.sh
scp environment/start_wayvnc.sh musepi:/home/bianbu/start_wayvnc.sh
ssh musepi "bash -n /home/bianbu/start_wayvnc.sh && chmod +x /home/bianbu/start_wayvnc.sh"
```

如果本机还没有镜像，先在板端创建最小脚本，之后再同步回本机镜像：

```bash
cat > /home/bianbu/start_wayvnc.sh <<'EOF'
#!/usr/bin/env bash
set -e
export XDG_RUNTIME_DIR=/run/user/$(id -u)
export WAYLAND_DISPLAY=${WAYLAND_DISPLAY:-wayland-0}
exec wayvnc 0.0.0.0 5900
EOF
chmod +x /home/bianbu/start_wayvnc.sh
```

重启后检查：

```bash
sudo reboot
```

```bash
loginctl
ls -l /run/user/1000/wayland-*
/home/bianbu/start_wayvnc.sh
```

VNC Viewer 连接：`192.168.137.194:5900`。无显示器时需要 HDMI dummy plug。

### 4. 源码同步

```powershell
cd E:\Embed_Game\MusePiPro_prj
ssh musepi "rm -rf /home/bianbu/k1muse_communicate_ros/src /home/bianbu/k1muse_slam_ros/src; mkdir -p /home/bianbu/k1muse_communicate_ros /home/bianbu/k1muse_slam_ros"
scp -r k1muse_communicate_ros/src musepi:/home/bianbu/k1muse_communicate_ros/
scp -r k1muse_slam_ros/src musepi:/home/bianbu/k1muse_slam_ros/
```

不要同步 `build/`、`install/`、`log/`、`.vscode/`、缓存和 `*.pyc`。

如果使用 `scp -r` 后发现缓存被带到板端，可只在板端源码目录内清理：

```bash
find /home/bianbu/k1muse_communicate_ros/src /home/bianbu/k1muse_slam_ros/src \( -type d -name __pycache__ -o -type d -name .pytest_cache \) -prune -exec rm -rf {} +
find /home/bianbu/k1muse_communicate_ros/src /home/bianbu/k1muse_slam_ros/src -type f -name '*.pyc' -delete
```

### 5. udev 串口别名

```bash
sudo cp /home/bianbu/k1muse_communicate_ros/src/udev/99-ros2-communicate.rules /etc/udev/rules.d/
sudo cp /home/bianbu/k1muse_slam_ros/src/udev/99-ros2-slam.rules /etc/udev/rules.d/
sudo udevadm control --reload-rules
sudo udevadm trigger
ls -l /dev/mymcu /dev/mylidar /dev/myimu
```

期望：

- `/dev/mymcu` -> UART4 `/dev/ttyS4`
- `/dev/mylidar` -> UART5 `/dev/ttyS5`
- `/dev/myimu` -> CH340 USB IMU

每条 udev 规则必须单行，不能在逗号后换行。

### 6. 设备树

目标：

- UART4：`/soc/uart@d4017300`，`status = okay`，`pinctrl-0 = <0x92>`，运行设备 `/dev/ttyS4`
- UART5：`/soc/uart@d4017400`，`status = okay`，`pinctrl-0 = <0x91>`，运行设备 `/dev/ttyS5`
- `uart4_3_grp`：`phandle = <0x92>`
- `uart5_3_grp`：`phandle = <0x91>`
- `/soc/pcie@ca800000`：UART4 复用引脚时设为 `disabled`

先备份板端当前文件：

```bash
sudo cp /boot/env_k1-x.txt /boot/env_k1-x.txt.pre-k1muse
sudo cp /boot/spacemit/6.6.63/k1-x_MUSE-Pi-Pro.dtb /boot/spacemit/6.6.63/k1-x_MUSE-Pi-Pro.dtb.pre-k1muse
```

如果是同一内核和同一镜像基线，可恢复本仓库镜像：

```powershell
cd E:\Embed_Game\MusePiPro_prj
scp device_tree/boot/env_k1-x.txt musepi:/tmp/env_k1-x.txt
scp device_tree/boot/spacemit/6.6.63/k1-x_MUSE-Pi-Pro.dtb musepi:/tmp/k1-x_MUSE-Pi-Pro.dtb
ssh musepi "sudo cp /tmp/env_k1-x.txt /boot/env_k1-x.txt && sudo cp /tmp/k1-x_MUSE-Pi-Pro.dtb /boot/spacemit/6.6.63/k1-x_MUSE-Pi-Pro.dtb && sync"
```

如果系统版本不确定，先基于板端当前 DTB 做最小修改，不直接覆盖旧 DTB：

```bash
dtc -I dtb -O dts -o /tmp/k1-x-current.dts /boot/spacemit/6.6.63/k1-x_MUSE-Pi-Pro.dtb
grep -nE 'uart@d4017300|uart@d4017400|uart4_3_grp|uart5_3_grp|pcie@ca800000' /tmp/k1-x-current.dts
```

修改 DTS 后编译并替换：

```bash
dtc -I dts -O dtb -o /tmp/k1-x_MUSE-Pi-Pro.dtb /tmp/k1-x-current.dts
sudo cp /tmp/k1-x_MUSE-Pi-Pro.dtb /boot/spacemit/6.6.63/k1-x_MUSE-Pi-Pro.dtb
sync
sudo reboot
```

重启后检查：

```bash
tr -d '\0' </proc/device-tree/soc/uart@d4017300/status
od -An -tx4 /proc/device-tree/soc/uart@d4017300/pinctrl-0
tr -d '\0' </proc/device-tree/soc/uart@d4017400/status
od -An -tx4 /proc/device-tree/soc/uart@d4017400/pinctrl-0
ls -l /dev/ttyS4 /dev/ttyS5 /dev/mymcu /dev/mylidar
```

期望：UART4 为 `okay` / `92000000`，UART5 为 `okay` / `91000000`。

### 7. 构建 MUSE

通信工作区先构建：

```bash
cd /home/bianbu/k1muse_communicate_ros
source /opt/ros/humble/setup.bash
colcon build
source install/setup.bash
```

再构建 SLAM 工作区：

```bash
cd /home/bianbu/k1muse_slam_ros
source /opt/ros/humble/setup.bash
source /home/bianbu/k1muse_communicate_ros/install/setup.bash
colcon build
source install/setup.bash
```

### 8. MUSE 自启动服务

#### 8.1 蓝牙配对 agent

手机端点击 `bianbu` 后完成配对，不需 K1 桌面端确认。

```bash
cd /home/bianbu/k1muse_communicate_ros
sudo cp install/k1muse_mobile_bridge/share/k1muse_mobile_bridge/systemd/k1-bluetooth-pairing-agent.service /etc/systemd/system/
sudo systemctl daemon-reload
sudo systemctl enable --now k1-bluetooth-pairing-agent.service
```

检查：

```bash
systemctl is-enabled k1-bluetooth-pairing-agent.service
systemctl is-active k1-bluetooth-pairing-agent.service
journalctl -u k1-bluetooth-pairing-agent.service -n 20 --no-pager
bluetoothctl show
bluetoothctl devices Trusted
```

期望：服务为 `enabled` / `active`，日志包含 `Bluetooth pairing agent ready`。

#### 8.2 App 蓝牙入口 supervisor

```bash
cd /home/bianbu/k1muse_communicate_ros
sudo cp install/k1muse_mobile_bridge/share/k1muse_mobile_bridge/systemd/k1-mobile-supervisor.service /etc/systemd/system/
sudo systemctl daemon-reload
sudo systemctl enable --now k1-mobile-supervisor.service
```

检查：

```bash
systemctl is-enabled k1-mobile-supervisor.service
systemctl is-active k1-mobile-supervisor.service
journalctl -u k1-mobile-supervisor.service -n 80 --no-pager
ls -l /dev/rfcomm0 2>/dev/null || true
```

期望：服务为 `enabled` / `active`。手机未连接时日志停在等待连接。

故障恢复：

```bash
sudo systemctl restart k1-mobile-supervisor.service
sudo rfcomm release /dev/rfcomm0 || true
sudo systemctl status k1-mobile-supervisor.service --no-pager
```

刷机后恢复顺序：先恢复 pairing agent，再恢复 mobile supervisor。

### 9. 最小硬件检查

串口原始数据：

```bash
stty -F /dev/mylidar 230400 raw -echo
timeout 3 dd if=/dev/mylidar bs=1 count=32 2>/dev/null | od -An -tx1

stty -F /dev/mymcu 115200 raw -echo
timeout 3 dd if=/dev/mymcu bs=1 count=32 2>/dev/null | od -An -tx1

stty -F /dev/myimu 115200 raw -echo
timeout 3 dd if=/dev/myimu bs=1 count=32 2>/dev/null | od -An -tx1
```

MCU 桥接 smoke test：

```bash
cd /home/bianbu/k1muse_communicate_ros
source /opt/ros/humble/setup.bash
source install/setup.bash
ros2 run k1muse_mcu_bridge mcu_bridge_node
```

另开终端：

```bash
source /opt/ros/humble/setup.bash
source /home/bianbu/k1muse_communicate_ros/install/setup.bash
ros2 topic echo --once /mcu/chassis/status
ros2 service list | grep /mcu/chassis
```

---

## 第二部分：树莓派 4B 计算端部署

### 10. 树莓派 OS 和基础环境

要求：Ubuntu 22.04 (Jammy) arm64，ROS2 Humble。

#### 10.1 网络配置

树莓派有线口 `eth0` 设为静态 IP `10.10.10.1/24`，用于 ROS2 数据面。Wi-Fi 连入局域网用于 SSH 管理。

netplan 示例 (`/etc/netplan/01-eth0.yaml`)：

```yaml
network:
  version: 2
  renderer: networkd
  ethernets:
    eth0:
      dhcp4: no
      addresses:
        - 10.10.10.1/24
```

```bash
sudo netplan apply
ip addr show eth0  # 确认 10.10.10.1/24
```

#### 10.2 MUSE 有线口配置

MUSE 有线口设为 `10.10.10.2/24`。MUSE 的 netplan 或 connman 配置取决于当前系统：

```bash
# 检查当前网络管理方式
ps aux | grep -E 'NetworkManager|connman|systemd-networkd'

# connman 方式
sudo connmanctl config ethernet_<mac>_cable --ipv4 manual 10.10.10.2 255.255.255.0

# 或用 ip 命令临时设置（重启失效）
sudo ip addr add 10.10.10.2/24 dev eth0
```

两端互 ping 验证：

```bash
# MUSE
ping -c 3 10.10.10.1

# 树莓派
ping -c 3 10.10.10.2
```

#### 10.3 MUSE 到树莓派 SSH 免密

```bash
# 在 MUSE 上生成密钥（如果没有）
ssh-keygen -t ed25519 -f ~/.ssh/id_ed25519 -N ""

# 把 MUSE 公钥写入树莓派
ssh-copy-id -i ~/.ssh/id_ed25519.pub user@10.10.10.1

# 验证免密
ssh user@10.10.10.1 "hostname"
```

#### 10.4 树莓派 ROS2 依赖

```bash
sudo apt-get update
sudo apt-get install -y \
  build-essential cmake git pkg-config \
  python3-pip python3-colcon-common-extensions \
  ros-humble-cartographer ros-humble-cartographer-ros ros-humble-cartographer-rviz \
  ros-humble-navigation2 ros-humble-nav2-bringup ros-humble-nav2-mppi-controller \
  ros-humble-nav2-map-server ros-humble-cartographer-ros-msgs \
  ros-humble-rviz2 ros-humble-rviz-imu-plugin ros-humble-xacro \
  ros-humble-robot-state-publisher ros-humble-tf2-ros \
  ros-humble-rmw-cyclonedds-cpp
```

#### 10.5 树莓派用户环境

```bash
grep -nE 'ROS|RMW|CYCLONEDDS' ~/.bashrc || true
cat >> ~/.bashrc <<'EOF'

# K1 remote compute ROS2 environment
source /opt/ros/humble/setup.bash
export ROS_DOMAIN_ID=42
export RMW_IMPLEMENTATION=rmw_cyclonedds_cpp
export ROS_LOCALHOST_ONLY=0
EOF
```

#### 10.6 CycloneDDS 数据面配置

树莓派 `/home/user/.ros/cyclonedds_eth.xml`：

```bash
mkdir -p ~/.ros
cat > ~/.ros/cyclonedds_eth.xml <<'EOF'
<CycloneDDS>
  <Domain>
    <General>
      <Interfaces>
        <NetworkInterface name="eth0" priority="default" multicast="default" />
      </Interfaces>
      <AllowMulticast>true</AllowMulticast>
    </General>
    <Discovery>
      <Peers>
        <Peer Address="10.10.10.2"/>
      </Peers>
    </Discovery>
  </Domain>
</CycloneDDS>
EOF
```

MUSE `/home/bianbu/.ros/cyclonedds_end.xml`：

```bash
mkdir -p ~/.ros
cat > ~/.ros/cyclonedds_end.xml <<'EOF'
<CycloneDDS>
  <Domain>
    <General>
      <NetworkInterfaceAddress>10.10.10.2</NetworkInterfaceAddress>
      <AllowMulticast>true</AllowMulticast>
    </General>
    <Discovery>
      <Peers>
        <Peer Address="10.10.10.1"/>
      </Peers>
    </Discovery>
  </Domain>
</CycloneDDS>
EOF
```

> 启动脚本会自动检测并 export `CYCLONEDDS_URI` 指向上述文件。

**验证 CycloneDDS 互通：**

```bash
# 树莓派
source /opt/ros/humble/setup.bash
export RMW_IMPLEMENTATION=rmw_cyclonedds_cpp CYCLONEDDS_URI=file://$HOME/.ros/cyclonedds_eth.xml
ros2 run demo_nodes_cpp talker &
```

```bash
# MUSE
source /opt/ros/humble/setup.bash
export ROS_DOMAIN_ID=42 RMW_IMPLEMENTATION=rmw_cyclonedds_cpp CYCLONEDDS_URI=file://$HOME/.ros/cyclonedds_end.xml
ros2 run demo_nodes_cpp listener
```

期望：MUSE 能收到树莓派发布的 `/chatter`。

### 11. 树莓派源码同步

```powershell
cd E:\Embed_Game\MusePiPro_prj
ssh -i C:\Users\YJY\.ssh\codex_musepi_ed25519 user@<树莓派Wi-Fi-IP> "rm -rf /home/user/k1muse_communicate_ros/src /home/user/k1muse_slam_ros/src; mkdir -p /home/user/k1muse_communicate_ros /home/user/k1muse_slam_ros"
scp -i C:\Users\YJY\.ssh\codex_musepi_ed25519 -r k1muse_communicate_ros/src user@<树莓派Wi-Fi-IP>:/home/user/k1muse_communicate_ros/
scp -i C:\Users\YJY\.ssh\codex_musepi_ed25519 -r k1muse_slam_ros/src user@<树莓派Wi-Fi-IP>:/home/user/k1muse_slam_ros/
```

如果树莓派 Wi-Fi IP 未知，也可通过 MUSE 有线中继：

```powershell
cd E:\Embed_Game\MusePiPro_prj
scp -r k1muse_communicate_ros/src musepi:/tmp/comm_src/
scp -r k1muse_slam_ros/src musepi:/tmp/slam_src/
ssh musepi "scp -r /tmp/comm_src user@10.10.10.1:/home/user/k1muse_communicate_ros/src && scp -r /tmp/slam_src user@10.10.10.1:/home/user/k1muse_slam_ros/src"
```

### 12. 树莓派构建

```bash
cd /home/user/k1muse_communicate_ros
source /opt/ros/humble/setup.bash
colcon build --packages-select k1muse_mcu_bridge
source install/setup.bash

cd /home/user/k1muse_slam_ros
source /opt/ros/humble/setup.bash
source /home/user/k1muse_communicate_ros/install/setup.bash
colcon build --packages-select imu_ros2_device ldlidar_stl_ros2 k1muse_description k1muse_slam_nav k1muse_exploration
source install/setup.bash
```

### 13. MPPI overlay 构建（树莓派）

> **必须执行**。树莓派上 ROS apt 包提供的 `libmppi_controller.so` 在 Cortex-A72 上触发 SIGILL (exit code -4)，会导致 `controller_server` 启动后立即崩溃，探索/导航无法工作。

#### 13.1 获取源码

```bash
# 本机
cd /tmp
git clone --depth 1 --branch humble https://github.com/ros-navigation/navigation2.git nav2_mppi_src
```

如果 GitHub 不可达，也可在树莓派上用 `apt source ros-humble-nav2-mppi-controller`（需配置 deb-src）。

#### 13.2 传到树莓派

```powershell
scp -r /tmp/nav2_mppi_src/nav2_mppi_controller musepi:/tmp/
```

```bash
# 在 MUSE 上
scp -r /tmp/nav2_mppi_controller user@10.10.10.1:/tmp/
```

#### 13.3 本机构建

```bash
# 在树莓派上
mkdir -p /tmp/mppi_ws/src
cp -r /tmp/nav2_mppi_controller /tmp/mppi_ws/src/
cd /tmp/mppi_ws
source /opt/ros/humble/setup.bash
colcon build --parallel-workers 1 --packages-select nav2_mppi_controller \
  --cmake-args -DBUILD_TESTING=OFF -DCMAKE_BUILD_TYPE=Release
```

> `--parallel-workers 1` 避免树莓派 4B (4GB RAM) OOM。构建耗时约 7 分钟。

#### 13.4 部署 overlay

```bash
rm -rf /home/user/mppi_overlay
cp -r /tmp/mppi_ws/install /home/user/mppi_overlay
ls /home/user/mppi_overlay/nav2_mppi_controller/lib/libmppi_controller.so
```

> MPPI overlay 由 `k1_start_map.sh` 和 `k1_start_exploration.sh` 的远程段自动 source。

#### 13.5 验证 MPPI 不会崩溃

```bash
source /opt/ros/humble/setup.bash
source /home/user/mppi_overlay/setup.bash
timeout 15 ros2 run nav2_controller controller_server --ros-args \
  --params-file /home/user/k1muse_slam_ros/src/k1muse_slam_nav/config/nav2_params.yaml
# 正常退出码 124 (timeout)，不应出现 exit code -4
```

### 14. 树莓派 swap（可选）

MPPI 构建和 Cartographer 运行时可能消耗较多内存。建议给树莓派 4B 添加 swap：

```bash
sudo fallocate -l 2G /swapfile
sudo chmod 600 /swapfile
sudo mkswap /swapfile
sudo swapon /swapfile
echo '/swapfile none swap sw 0 0' | sudo tee -a /etc/fstab
```

---

## 第三部分：全系统集成验证

### 15. 分布式建图 smoke test

清理上一轮进程：

```bash
# MUSE
/home/bianbu/k1muse_slam_ros/install/k1muse_exploration/lib/k1muse_exploration/k1_stop_exploration.sh fast || true
/home/bianbu/k1muse_slam_ros/install/k1muse_slam_nav/lib/k1muse_slam_nav/k1_stop_mapping.sh fast || true
/home/bianbu/k1muse_communicate_ros/install/k1muse_mcu_bridge/lib/k1muse_mcu_bridge/k1_stop_mcu_bridge.sh || true
```

启动建图：

```bash
source /opt/ros/humble/setup.bash
source /home/bianbu/k1muse_communicate_ros/install/setup.bash
source /home/bianbu/k1muse_slam_ros/install/setup.bash
k1_start_mapping.sh
```

验证数据流：

```bash
export ROS_DOMAIN_ID=42 RMW_IMPLEMENTATION=rmw_cyclonedds_cpp ROS_LOCALHOST_ONLY=0

# 数据速率
ros2 topic hz /scan        # 期望 ~10 Hz
ros2 topic hz /odom        # 期望 ~20 Hz
ros2 topic hz /imu/data    # 期望 ~10 Hz

# 地图
timeout 10 ros2 topic echo --once /map --field info

# TF
ros2 run tf2_ros tf2_echo map base_footprint
ros2 run tf2_ros tf2_echo odom base_footprint

# 树莓派进程
ssh user@10.10.10.1 "pgrep -af 'cartographer|occupancy_grid'"
```

停止建图：

```bash
k1_save_map.sh manual
k1_stop_mapping.sh fast
```

### 16. 分布式探索 smoke test

```bash
k1_start_exploration.sh -2.3 3.0 -1.2 2.35
```

验证节点（期望所有 6 个关键节点可见）：

```bash
export ROS_DOMAIN_ID=42 RMW_IMPLEMENTATION=rmw_cyclonedds_cpp ROS_LOCALHOST_ONLY=0
ros2 node list | grep -E 'cartographer_node|cartographer_occupancy|controller_server|planner_server|bt_navigator|rrt_frontier'
```

检查树莓派 controller_server 进程（不应崩溃）：

```bash
ssh user@10.10.10.1 "pgrep -af controller_server"
# 期望：有 pid 输出，说明 MPPI 正常
```

检查探索日志：

```bash
ssh user@10.10.10.1 "tail -n 40 /home/user/.ros/k1muse_exploration/logs/exploration.log | grep -E 'controller_server|rrt_frontier|goal|error|ERROR'"
# 期望：有 "Sent exploration goal"，无 "process has died"
```

停止探索：

```bash
k1_stop_exploration.sh fast
```

---

## 第四部分：回退和故障排查

### 17. 回退到 MUSE 本地计算

如果树莓派不可用或需要测试 MUSE 单机模式：

```bash
K1_REMOTE_COMPUTE=0 k1_start_mapping.sh
K1_REMOTE_COMPUTE=0 K1_MAPPING_USE_RVIZ=true k1_start_mapping.sh
K1_REMOTE_COMPUTE=0 k1_save_map.sh manual
K1_REMOTE_COMPUTE=0 k1_stop_mapping.sh fast
K1_REMOTE_COMPUTE=0 k1_start_exploration.sh -2.3 3.0 -1.2 2.35
K1_REMOTE_COMPUTE=0 k1_stop_exploration.sh fast
```

注意：MUSE 本地计算性能远低于树莓派，Cartographer/Nav2 会加重 MUSE 负载。

### 18. 回退 MPPI overlay

如果 overlay 导致问题，恢复系统 MPPI（会再次 SIGILL）：

```bash
ssh user@10.10.10.1 "rm -rf /home/user/mppi_overlay"
```

然后从 `k1_start_map.sh` 和 `k1_start_exploration.sh` 中删除 `source /home/user/mppi_overlay/setup.bash` 行。

恢复后探索/导航不可用（controller 崩溃），但建图仍正常工作。

### 19. 常见故障排查

#### 19.1 ros2 node list/topic list 无输出或很慢

ROS2 CLI 在 RISC-V 上很慢。设置环境变量后再试：

```bash
export ROS_DOMAIN_ID=42 RMW_IMPLEMENTATION=rmw_cyclonedds_cpp ROS_LOCALHOST_ONLY=0
```

也可直接检查进程而非通过 ros2 CLI：

```bash
# MUSE
pgrep -af 'mcu_bridge|lidar|ldlidar|ybimu|robot_state|scan_self'

# 树莓派
ssh user@10.10.10.1 "pgrep -af 'cartographer|controller_server|planner|bt_navigator|rrt_frontier'"
```

#### 19.2 controller_server exit code -4

树莓派上 MPPI overlay 未构建或未正确 source。检查：

```bash
ssh user@10.10.10.1 "ls -la /home/user/mppi_overlay/nav2_mppi_controller/lib/libmppi_controller.so"
```

如果文件存在但问题仍存在，检查 `k1_start_exploration.sh` 远程段是否包含：

```bash
source /home/user/mppi_overlay/setup.bash 2>/dev/null || true
```

#### 19.3 建图/探索启动超时

查看对应日志获取具体错误：

```bash
# MUSE
tail -n 80 /home/bianbu/.ros/k1muse_slam_nav/logs/slam_mapping.log

# 树莓派
ssh user@10.10.10.1 "tail -n 80 /home/user/.ros/k1muse_slam_nav/logs/slam_mapping.log"
ssh user@10.10.10.1 "tail -n 80 /home/user/.ros/k1muse_exploration/logs/exploration.log"
```

常见原因：

- `/odom` 不可见 → 检查 MCU bridge 是否启动、`/dev/mymcu` 是否存在
- Cartographer 不启动 → 检查 `/scan`、`/odom`、`/imu/data` 是否都有数据
- 树莓派 SSH 不通 → 检查有线连接、IP 配置、SSH key
- ROS2 节点发现不到 → 检查 `ROS_DOMAIN_ID=42`、CycloneDDS 配置、网络互通

#### 19.4 树莓派有线 SSH 超时

可能原因：树莓派系统负载过高（编译或其他进程）。处理：

1. 等待 1-2 分钟让进程自然结束
2. 通过 Wi-Fi IP SSH 进去 `sudo reboot`
3. 检查 MUSE 有线口配置 `ip addr show eth0`

#### 19.5 蓝牙地图传输慢/遥控延迟

- 确认 `mobile_bridge_node` 使用了最新配置（`tile_size: 32` 等）
- 重启 supervisor：`sudo systemctl restart k1-mobile-supervisor.service`
- 检查 RFCOMM 设备：`ls -l /dev/rfcomm0`

#### 19.6 App 连接不上/MUSE 蓝牙不可见

```bash
systemctl status k1-bluetooth-pairing-agent.service
systemctl status k1-mobile-supervisor.service
journalctl -u k1-bluetooth-pairing-agent.service -n 30 --no-pager
bluetoothctl show  # 确认 Powered: yes, Discoverable: yes
```

如果 pairing agent 未运行：`sudo systemctl restart k1-bluetooth-pairing-agent.service`
如果 supervisor 未运行：`sudo systemctl restart k1-mobile-supervisor.service`

---

## 附录 A：全部文件路径速查

### MUSE (`/home/bianbu/`)

```
k1muse_communicate_ros/
├── src/           ← 同步自本机 k1muse_communicate_ros/src/
├── build/
├── install/
└── log/

k1muse_slam_ros/
├── src/           ← 同步自本机 k1muse_slam_ros/src/
├── build/
├── install/
└── log/

.ros/
├── cyclonedds_end.xml     ← CycloneDDS MUSE 配置
├── k1muse_slam_nav/run/   ← 建图 PID
├── k1muse_slam_nav/logs/  ← 建图日志
├── k1muse_exploration/run/  ← 探索 PID
└── k1muse_exploration/logs/ ← 探索日志

~/.bashrc
~/start_wayvnc.sh
```

### 树莓派 (`/home/user/`)

```
k1muse_communicate_ros/
├── src/           ← 同步自本机
├── build/
└── install/

k1muse_slam_ros/
├── src/           ← 同步自本机
├── build/
└── install/

mppi_overlay/           ← MPPI 本机构建 overlay
└── nav2_mppi_controller/lib/
    ├── libmppi_controller.so
    └── libmppi_critics.so

.ros/
├── cyclonedds_eth.xml     ← CycloneDDS 树莓派配置
├── k1muse_slam_nav/run/   ← 建图 PID
├── k1muse_slam_nav/logs/  ← 建图日志
├── k1muse_exploration/run/  ← 探索 PID
└── k1muse_exploration/logs/ ← 探索日志

~/.bashrc
/swapfile                ← 可选 2GB swap
```

## 附录 B：依赖版本锁定

| 包 | 版本 | 架构 | 说明 |
|---|---|---|---|
| ROS2 | Humble | riscv64 / aarch64 | 主线 ROS2 版本 |
| Cartographer | humble package | riscv64 / aarch64 | apt 安装 |
| Nav2 | humble package | aarch64 | 仅树莓派 |
| Nav2 MPPI | 1.1.20 (overlay rebuild) | aarch64 | 树莓派本机重编，替代 apt 包 |
| CycloneDDS | humble package | riscv64 / aarch64 | ROS2 RMW |
| 内核 (MUSE) | 6.6.63 | riscv64 | 固定版本，DTB 绑定 |
| 内核 (RPi) | Ubuntu Jammy 默认 | aarch64 | 不锁定 |

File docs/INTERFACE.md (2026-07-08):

# MUSE Pi Pro 工作区外部接口

本文只描述本工作区对外暴露的稳定接口，以及外部系统应该如何使用这些接口。

## 工作区入口

- 本机仓库：`E:\Embed_Game\MusePiPro_prj`
- 板端通信工作区：`/home/bianbu/k1muse_communicate_ros/`
- 板端 SLAM 工作区：`/home/bianbu/k1muse_slam_ros/`
- 树莓派计算工作区：`/home/user/k1muse_slam_ros/`
- 树莓派 MPPI overlay：`/home/user/mppi_overlay/`
- 通信源码：`k1muse_communicate_ros/src/`
- SLAM/Nav 源码：`k1muse_slam_ros/src/`
- 地图目录：`/home/bianbu/k1muse_slam_ros/src/k1muse_slam_nav/maps/`

外部系统不要直接依赖 `build/`、`install/`、`log/`、缓存目录或开发临时脚本目录。板端运行前按 `AGENTS.md` 和 `ENV_DEV.md` 同步源码并构建。

默认运行是双机分布式：

- MUSE Pi Pro：硬件桥接、传感器发布、蓝牙 App、地图目录、手动 RViz。
- Raspberry Pi 4B：Cartographer、Nav2、自动探索和地图保存计算。

外部系统仍以 MUSE 为唯一产品入口。树莓派只作为内部计算端，不改变 Android App 协议、脚本名称、地图目录语义或 ROS2 topic/service/action 名称。

## 硬件设备接口

| 设备 | 板端别名 | 物理设备 | 用途 | 独占方 |
|---|---|---|---|---|
| STM32 MCU | `/dev/mymcu` | UART4 `/dev/ttyS4`，115200 8N1 | 底盘状态和控制 | `mcu_bridge_node` |
| LD06 | `/dev/mylidar` | UART5 `/dev/ttyS5`，230400 8N1 | 激光雷达 | `ldlidar_stl_ros2` |
| YB IMU | `/dev/myimu` | CH340 USB 串口，115200 8N1 | IMU 数据 | `imu_ros2_device` |
| Android App | `/dev/rfcomm0` | Bluetooth RFCOMM/SPP | 手机桥接 | `mobile_supervisor.py` 或 `mobile_bridge_node` |

STM32 串口只能由 `mcu_bridge_node` 独占打开。外部底盘、机械臂、升降、导航或 App 逻辑通过 ROS2 topic/service/action 访问，不直接抢 `/dev/mymcu`。

## 网络拓扑

```
MUSE Pi Pro (192.168.137.194 Wi-Fi / 10.10.10.2 eth)  ←→  Raspberry Pi 4B (10.10.10.1 eth)
       ↑ Wi-Fi SSH 管理面                                        ↑ Wi-Fi DHCP 管理面
       ↑ 10.10.10.0/24 有线 ROS2 数据面 (CycloneDDS peer)
```

两端 CycloneDDS 配置文件确保 ROS2 数据面走有线，内容详见 `AGENTS.md`。

## 坐标和 TF

坐标遵循 REP-103：`+X` 前、`+Y` 左、`+Z` 上，yaw 逆时针为正。

目标 TF 树：

```text
map -> odom -> base_footprint -> base_link -> base_laser
       ↑                                        ↑
  Cartographer                              -> imu_link
  (或 Nav2/AMCL)
```

- `odom -> base_footprint`：由 `k1muse_mcu_bridge/mcu_bridge_node` 发布。
- `base_footprint -> base_link -> base_laser / imu_link`：由 `k1muse_description` 的 URDF 经 `robot_state_publisher` 发布。
- `map -> odom`：建图时由 Cartographer 发布，导航时由 Nav2/AMCL 发布。

## ROS2 Topic

| Topic | 类型 | 方向 | 说明 |
|---|---|---|---|
| `/mcu/chassis/status` | `k1muse_mcu_bridge/msg/ChassisStatus` | MCU -> ROS | 底盘状态原始上行数据 |
| `/mcu/chassis/mov` | `k1muse_mcu_bridge/msg/ChassisMov` | ROS -> MCU bridge | 底盘 MOV 下行命令 |
| `/cmd_vel` | `geometry_msgs/msg/Twist` | 外部控制 -> MCU bridge | 可选速度控制入口，需 `mcu_bridge_node enable_cmd_vel_output:=true` |
| `/cmd_vel_nav` | `geometry_msgs/msg/Twist` | Nav2 -> (remap) | Nav2 controller 输出的速度指令，由 launch 文件 remap 到 `/cmd_vel` |
| `/odom` | `nav_msgs/msg/Odometry` | MCU bridge -> ROS | 里程计，child frame 为 `base_footprint` |
| `/scan_raw` | `sensor_msgs/msg/LaserScan` | LD06 -> ROS | 原始雷达扫描，frame 为 `base_laser` |
| `/scan` | `sensor_msgs/msg/LaserScan` | 过滤节点 -> ROS | 过滤自车体后的雷达扫描，供 Cartographer/Nav2/App 使用 |
| `/imu/data` | `sensor_msgs/msg/Imu` | IMU -> ROS | IMU 数据，frame 为 `imu_link` |
| `/map` | `nav_msgs/msg/OccupancyGrid` | Cartographer/Nav2 -> ROS/App | 当前地图 |
| `/plan` | `nav_msgs/msg/Path` | Nav2 -> App | 自动探索时发送给 App 的路径 |
| `/goal_pose` | `geometry_msgs/msg/PoseStamped` | rrt_frontier_explorer -> Nav2 | 自动探索目标位姿 |
| `/exploration_status` | `std_msgs/msg/String` | 自动探索 -> ROS/App | 自动探索状态文本 |
| `/exploration_markers` | `visualization_msgs/msg/MarkerArray` | 自动探索 -> RViz | 自动探索候选点和目标可视化 |

## ROS2 Service

| Service | 类型 | 说明 |
|---|---|---|
| `/mcu/chassis/stop` | `k1muse_mcu_bridge/srv/ChassisStop` | 向 MCU 发送底盘停止命令 |
| `/mcu/chassis/odom` | `k1muse_mcu_bridge/srv/ChassisOdom` | 向 MCU 写入底盘 odom 重置值：`direction`、`x`、`y` |
| `/write_state` | `cartographer_ros_msgs/srv/WriteState` | Cartographer 保存 `.pbstream` |

## ROS2 Action

| Action | 类型 | 使用方 |
|---|---|---|
| `navigate_to_pose` | `nav2_msgs/action/NavigateToPose` | Nav2 提供，`k1muse_exploration` 可向它发送自动探索目标 |

## 启动脚本接口

安装后的脚本是 App、systemd 或人工操作应优先使用的稳定入口。

| 脚本 | 工作区 | 说明 |
|---|---|---|
| `k1_start_mcu_bridge.sh` | communication | 启动 MCU bridge，默认开启 `/cmd_vel` 到 MCU 的路由 |
| `k1_stop_mcu_bridge.sh` | communication | 发布零 `/cmd_vel` 后停止 MCU bridge |
| `k1_start_mapping.sh` | slam | 启动 MCU bridge、传感器和 Cartographer 建图（默认远程） |
| `k1_save_map.sh manual` | slam | 保存 `manual_*.yaml/.pgm/.pbstream`，远程模式下由树莓派计算后同步回 MUSE 地图目录 |
| `k1_stop_mapping.sh` | slam | 停止前尝试保存 `stop_*`，失败也继续停止 |
| `k1_stop_mapping.sh fast` | slam | 快速停止，不做自动保存 |
| `k1_start_exploration.sh MIN_X MAX_X MIN_Y MAX_Y` | slam | 在指定边界内启动自动探索 |
| `k1_stop_exploration.sh fast` | slam | 快速停止自动探索和 MCU bridge |
| `k1_stop_exploration.sh save` | slam | 停止前调用 `k1_save_map.sh manual` |

远程计算模式下，启动脚本会检查树莓派关键节点后再返回成功。建图至少要求 Cartographer 和 occupancy grid 节点可见；自动探索还要求 Nav2 controller、planner、BT navigator 和 `rrt_frontier_explorer` 可见。等待超时后输出日志尾部帮助定位问题。

脚本状态和日志：

- 建图：`/home/bianbu/.ros/k1muse_slam_nav/run/`、`/home/bianbu/.ros/k1muse_slam_nav/logs/`
- 自动探索：`/home/bianbu/.ros/k1muse_exploration/run/`、`/home/bianbu/.ros/k1muse_exploration/logs/`
- 树莓派计算端日志：`/home/user/.ros/k1muse_slam_nav/logs/`、`/home/user/.ros/k1muse_exploration/logs/`

远程编排环境变量：

| 变量 | 默认值 | 说明 |
|---|---|---|
| `K1_REMOTE_COMPUTE` | `1` | `1` 使用树莓派计算端；`0` 回退到 MUSE 本地运行 Cartographer/Nav2/探索 |
| `K1_REMOTE_SLAM_HOST` | `user@10.10.10.1` | MUSE 到树莓派的 SSH 目标 |
| `K1_REMOTE_COMMS_WS` | `/home/user/k1muse_communicate_ros` | 树莓派通信工作区，用于 source 接口包 |
| `K1_REMOTE_SLAM_WS` | `/home/user/k1muse_slam_ros` | 树莓派 SLAM 工作区 |
| `K1_REMOTE_STATE_DIR` | `/home/user/.ros/k1muse_slam_nav` | 树莓派建图日志和 pid 目录 |
| `K1_REMOTE_EXPLORATION_STATE_DIR` | `/home/user/.ros/k1muse_exploration` | 树莓派探索日志和 pid 目录 |
| `K1_MAPPING_USE_RVIZ` | `false` | `K1_REMOTE_COMPUTE=0` 本地建图时是否随 `k1_start_mapping.sh` 启动 RViz；远程计算仍固定不自动启动 RViz |
| `K1_EXPLORE_USE_RVIZ` | `false` | 本地或远程探索 launch 是否请求 RViz；App 默认不设置 |
| `K1_SKIP_ODOM_PREFLIGHT` | `0` | `1` 跳过 MCU bridge 后的 `/odom` 可见性等待 |
| `K1_MAPPING_USE_RVIZ` | `false` | 本地建图时是否随脚本启动 RViz |

`slam.launch.py`、`nav.launch.py` 和 `explore.launch.py` 支持 `start_sensors:=false`。树莓派计算端必须使用该参数，避免尝试打开 MUSE 上的 `/dev/mylidar`、`/dev/myimu` 或 `/dev/mymcu`。

## App 蓝牙接口

`k1muse_mobile_bridge` 使用经典蓝牙 RFCOMM/SPP。帧格式固定为：

```text
magic[4] = "K1MB"
version  = 1
type     = uint8
flags    = uint16
seq      = uint32
len      = uint32
crc32    = uint32 payload CRC32
payload  = len bytes
```

所有数值小端序。`magic` 按 `K1MB` 原样写入。

### 帧优先级

发送队列使用两级优先级控制蓝牙带宽：

| 优先级 | 帧类型 | 说明 |
|---|---|---|
| `NORMAL` | `HELLO`, `HEARTBEAT`, `ROBOT_POSE`, `BRIDGE_STATUS`, `MAP_CONTROL_STATUS`, `TELEOP_CMD` 回执 | 正常发送，不限制 |
| `LOW` | `MAP_TILE`, `MAP_INFO`, `NAV_PATH`, `MAP_LIBRARY_LIST` | 受队列限制 |

遥控活跃时（最近 1.5s 内收到 `TELEOP_CMD`），所有 `LOW` 帧从队列清除并不再入队，确保遥控指令不被地图数据阻塞。

### 主要消息类型

| 类型 | 数值 | 方向 | 说明 |
|---|---:|---|---|
| `HELLO` | `0x01` | K1 -> App | 链路问候 |
| `HEARTBEAT` | `0x02` | K1 -> App | 心跳 |
| `MAP_INFO` | `0x10` | K1 -> App | 地图元信息（宽、高、分辨率、origin） |
| `MAP_TILE` | `0x11` | K1 -> App | 地图 tile，支持 raw/zlib 编码 |
| `ROBOT_POSE` | `0x20` | K1 -> App | `map -> base_footprint` 位姿（复合 TF 查询） |
| `TELEOP_CMD` | `0x30` | App -> K1 | `vx`、`vy`、`omega` 手动速度 |
| `STOP` | `0x31` | App -> K1 | 发布零 `/cmd_vel` |
| `NAV_PATH` | `0x43` | K1 -> App | 自动探索/导航路径抽样 |
| `BRIDGE_CONTROL` | `0x48` | App -> K1 | 启动、停止、查询 full bridge |
| `BRIDGE_STATUS` | `0x49` | K1 -> App | bridge 状态 |
| `MAP_CONTROL` | `0x50` | App -> K1 | 建图启动、保存、停止、查询 |
| `MAP_CONTROL_STATUS` | `0x51` | K1 -> App | 建图状态和保存路径 |
| `MAP_LIBRARY_REQUEST` | `0x60` | App -> K1 | 地图库列表、加载、区域读写 |
| `MAP_LIBRARY_STATUS` | `0x61` | K1 -> App | 地图库命令结果 |
| `MAP_LIBRARY_LIST` | `0x62` | K1 -> App | 地图库 `.yaml` 列表 |
| `MAP_REGIONS_DATA` | `0x63` | K1 -> App | 地图区域 JSON |
| `ERROR` | `0x7F` | K1 -> App | 协议错误 |

### MAP_CONTROL 命令

| 命令 | 数值 | 说明 |
|---|---:|---|
| `START_MAPPING` | `1` | 启动正式建图脚本 |
| `SAVE_MAP_MANUAL` | `2` | 保存 `manual_*` 地图 |
| `STOP_MAPPING` | `3` | 当前 App 路径使用 `k1_stop_mapping.sh fast` |
| `QUERY_MAPPING` | `4` | 查询建图状态 |

### MAP_LIBRARY_REQUEST 命令

| 命令 | 数值 | 说明 |
|---|---:|---|
| `LIST_MAPS` | `1` | 列出地图目录下的 `.yaml/.yml` |
| `LOAD_MAP` | `2` | 读取指定地图并通过 `MAP_INFO/MAP_TILE` 发送 |
| `READ_REGIONS` | `3` | 读取同名 `.regions.json` |
| `SAVE_REGIONS` | `4` | 保存同名 `.regions.json` |

### 地图传输参数

这些参数在 `mobile_bridge.yaml` 中配置，影响蓝牙地图传输性能：

| 参数 | 默认值 | 说明 |
|---|---|---|
| `tile_size` | 32 | 每 tile 像素边长，影响每帧大小 |
| `max_queue_frames` | 64 | 发送队列最大帧数 |
| `max_low_queue_frames` | 4 | LOW 优先级帧最大排队数 |
| `max_map_tiles_per_update` | 8 | 每次 `/map` 回调最多发送 tile 数 |
| `map_publish_hz` | 2.0 | 地图变化检查频率 |
| `pose_publish_hz` | 10.0 | 机器人位姿发送频率 |
| `path_publish_hz` | 1.0 | 导航路径发送频率 |
| `teleop_timeout_ms` | 300 | 遥控超时后自动停止（ms） |

### ROBOT_POSE TF 查询机制

`send_pose()` 使用 2D 复合 TF fallback 策略：

1. 先直接查 `map -> base_footprint` at `TimePointZero`（一次查询）
2. 失败时分别查 `map -> odom` 和 `odom -> base_footprint` at `TimePointZero`，用 2D 合成 `(x, y, yaw)`

这避免了因 `map -> odom` 和 `odom -> base_footprint` 缓存时间不重叠导致的位姿发送卡住。

## 外部使用规则

- 需要控制底盘时，先确认 `mcu_bridge_node` 以 `enable_cmd_vel_output:=true` 运行。
- 只读建图或外部遥控时，保持 `enable_cmd_vel_output:=false`，避免板端向 MCU 输出控制。
- 不要从外部直接操作树莓派上的地图文件作为 App 地图库；App 地图库以 MUSE 的 `maps/` 目录为准。
- MUSE 手动 RViz 只需要订阅分布式 ROS graph 中的 `/map`、`/scan`、`/odom` 和 TF，不需要在 App 启动时自动打开。
- SLAM/Nav 只消费过滤后的 `/scan`，单独调试雷达时才使用独立 `ld06.launch.py` 的 `/scan`。
- IMU 当前不参与 `/odom` 融合，只作为 Cartographer 可选输入。
- 地图保存后同步回本机仓库，再纳入 Git。
- 不要把 `/home/bianbu/tmp_sh` 当作产品入口。
- 树莓派上的 MPPI overlay（`/home/user/mppi_overlay/`）是必要的运行时补丁，删除后探索/导航的 `controller_server` 会因 SIGILL 崩溃。

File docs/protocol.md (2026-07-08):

# Communication Protocol

本文档定义机器人外部控制通信协议。当前定义 `SYSTEM`、`CHASSIS`、`ARM` 和 `LIFT`，其中 `SYSTEM` 暂不定义具体命令。

## 1. 基本约定

- 协议类型：二进制帧
- 数据字节序：little-endian
- 浮点数：IEEE754 float32，4 bytes
- payload 结构体：1 byte packed，对齐后长度必须与 `LEN` 一致
- payload 最大长度：`64` bytes
- 校验：CRC-8/ATM

CRC-8/ATM 参数：

| 参数 | 值 |
| --- | --- |
| poly | `0x07` |
| init | `0x00` |
| xorout | `0x00` |
| refin | `false` |
| refout | `false` |

## 2. 帧格式

```text
SOF1 SOF2 SRC TARGET CMD SEQ LEN PAYLOAD CRC8
```

| 字段 | 长度 | 值/说明 |
| --- | ---: | --- |
| `SOF1` | 1 | `0xA5` |
| `SOF2` | 1 | `0x5A` |
| `SRC` | 1 | 命令来源 |
| `TARGET` | 1 | 目标模块 |
| `CMD` | 1 | 模块命令 |
| `SEQ` | 1 | 帧序号，发送端递增 |
| `LEN` | 1 | payload 长度，`0..64` |
| `PAYLOAD` | `LEN` | 命令载荷 |
| `CRC8` | 1 | CRC8 校验 |

CRC8 计算范围：

```text
SRC TARGET CMD SEQ LEN PAYLOAD
```

不包含 `SOF1`、`SOF2`、`CRC8`。

## 3. 通用枚举

### 3.1 SRC

```c
typedef enum {
    CTRL_SRC_NONE = 0x00,
    CTRL_SRC_BT = 0x01,
    CTRL_SRC_HOST = 0x02,
    CTRL_SRC_MCU = 0x10,
} control_source_e;
```

### 3.2 TARGET

```c
typedef enum {
    CTRL_TARGET_SYSTEM = 0x00,
    CTRL_TARGET_CHASSIS = 0x01,
    CTRL_TARGET_ARM = 0x02,
    CTRL_TARGET_LIFT = 0x03,
    CTRL_TARGET_PERIPHERAL = 0x04,
} ctrl_target_e;
```

### 3.3 MCU 上报调度

底盘、机械臂和升降任务的执行周期均保持为 `10 ms`，状态采样和控制计算周期不因 telemetry 调度而改变。周期 `STATUS` 的提交周期为 `50 ms`，相位安排如下：

| 模块 | 任务周期 | `STATUS` 周期 | 首次提交相位 |
| --- | ---: | ---: | ---: |
| CHASSIS | `10 ms` | `50 ms` | `0 ms` |
| ARM | `10 ms` | `50 ms` | `20 ms` |
| LIFT | `10 ms` | `50 ms` | `40 ms` |
| PERIPHERAL | `10 ms` | `50 ms` | `10 ms` |

首次提交相位相对各模块任务启动时刻计算，用于避免三个模块在同一任务周期集中提交状态帧。上位机不应依赖严格的帧间隔或固定到达顺序，应使用各 payload 中的 `tick_ms` 判断状态采样时间。

MCU 将上报分为两类进行调度：

| 类型 | 触发方式 | 缓存方式 | 调度规则 |
| --- | --- | --- | --- |
| `RESULT` | 命令处理事件触发 | 独立 FIFO 队列 | 优先于 `STATUS` 发送，保持入队顺序，不参与 `STATUS` 轮询和覆盖 |
| `STATUS` | 周期触发 | 每个模块一个最新值槽位 | 无 `RESULT` 待发送时按模块轮询；同模块尚未发送的旧状态可被新状态覆盖 |

`RESULT` 入队最多等待 `5 ms`；若队列持续满载，提交函数返回失败。`STATUS` 的最新值策略可能跳过中间状态快照，但不会影响模块任务的控制周期。上位机应将 `RESULT` 用作命令结果依据，将 `STATUS` 用作当前状态快照，不应通过统计 `STATUS` 帧数判断命令是否完成。

每个上报帧仍通过同一 telemetry 发送任务广播到蓝牙串口和上位机串口。串口发送忙时，telemetry 任务分别等待各串口可接受当前帧，不因正常的 UART busy 直接丢弃该帧；两路串口共享同一帧内容和 `SEQ`。若某一路串口长期无法恢复可发送状态，后续 telemetry 上报会被阻塞。

## 4. SYSTEM

`SYSTEM` 用于系统级宏命令。当前已定义比赛演示宏命令，正式上位机接口走 `USART2`，帧内 `SRC` 必须为 `CTRL_SRC_HOST = 0x02`。蓝牙调试口走 `USART3`，帧内 `SRC` 必须为 `CTRL_SRC_BT = 0x01`。下位机会校验物理串口和 `SRC` 是否匹配，不匹配的帧会被丢弃。

### 4.1 CMD

```c
typedef enum {
    CTRL_SYS_CMD_RESERVED = 0x00,
    CTRL_SYS_CMD_DEMO_STOP = 0x01,
    CTRL_SYS_CMD_DEMO_RUN = 0x02,
    CTRL_SYS_CMD_DEMO_HOME = 0x03,
    CTRL_SYS_RPT_DEMO_STATUS = 0x80,
    CTRL_SYS_RPT_DEMO_RESULT = 0x81,
} ctrl_system_cmd_e;
```

### 4.2 Demo Variant

```c
typedef enum {
    CTRL_DEMO_VARIANT_AUTO = 0x00,
    CTRL_DEMO_VARIANT_DOWN = 0x01,
    CTRL_DEMO_VARIANT_UP = 0x02,
} ctrl_demo_variant_e;
```

| `variant` | 含义 |
| ---: | --- |
| `0x00` | `AUTO`，根据 `src_layer` / `dst_layer` 自动推断路线 |
| `0x01` | `DOWN`，下行标定，主要用于 `3 -> 2` |
| `0x02` | `UP`，上行标定，主要用于 `2 -> 3`，当前三层目标约上调 `0.02 m` |

`DEMO_ID_LAYER_TRANSFER` 使用 `AUTO` 时，若 `dst_layer > src_layer` 则按 `UP` 处理；若 `dst_layer < src_layer` 则按 `DOWN` 处理。

### 4.3 Demo ID

```c
typedef enum {
    DEMO_ID_NONE = 0x00,
    DEMO_ID_STATIC_PICK_PLACE = 0x01,
    DEMO_ID_LAYER_PICK = 0x02,
    DEMO_ID_LAYER_PLACE = 0x03,
    DEMO_ID_LAYER_TRANSFER = 0x04,
    DEMO_ID_KEY_TURN = 0x05,
    DEMO_ID_CABINET_PULL = 0x06,
} demo_id_e;
```

| `demo_id` | 含义 | `src_layer` | `dst_layer` |
| ---: | --- | --- | --- |
| `0x01` | 平面抓取放置 | `0` | `0` |
| `0x02` | 从指定层抓取 | 抓取层 `1..3` | `0` |
| `0x03` | 放置到指定层 | `0` | 放置层 `1..3` |
| `0x04` | 层间搬运 | 源层 `1..3` | 目标层 `1..3` |
| `0x05` | 钥匙旋转拉出 | `0` | `0` |
| `0x06` | 夹柜门后拉 | `0` | `0` |

### 4.4 DEMO_RUN

`CTRL_SYS_CMD_DEMO_RUN = 0x02`，payload 长度固定为 `4` bytes：

```c
typedef struct {
    uint8_t demo_id;
    uint8_t src_layer;
    uint8_t dst_layer;
    uint8_t variant;
} ctrl_demo_run_payload_t;
```

下位机收到合法 `DEMO_RUN` 后会封装为内部 `demo_cmd_msg_t` 并放入 `DemoCmdQueue`，由 `DemoTask` 选择对应动作步骤表执行。上位机不需要逐条下发 ARM / LIFT / CHASSIS 动作。

正式上位机 `USART2` 示例，假设 `SRC = 0x02`、`SEQ = 0x01`：

```text
STATIC_PICK_PLACE:
A5 5A 02 00 02 01 04 01 00 00 00 FB

LAYER_TRANSFER 3 -> 2, DOWN:
A5 5A 02 00 02 01 04 04 03 02 01 25

LAYER_TRANSFER 2 -> 3, UP:
A5 5A 02 00 02 01 04 04 02 03 02 52

LAYER_TRANSFER 2 -> 3, AUTO:
A5 5A 02 00 02 01 04 04 02 03 00 5C

KEY_TURN:
A5 5A 02 00 02 01 04 05 00 00 00 A3

CABINET_PULL:
A5 5A 02 00 02 01 04 06 00 00 00 94
```

若通过蓝牙调试口 `USART3` 测试，则 `SRC` 改为 `0x01` 并重新计算 CRC。

### 4.5 DEMO_STOP / DEMO_HOME

`CTRL_SYS_CMD_DEMO_STOP = 0x01`，payload 长度为 `0`，用于中止当前 demo。

`CTRL_SYS_CMD_DEMO_HOME = 0x03`，payload 长度为 `0`，用于执行 demo 归位链。

正式上位机 `USART2` 示例，假设 `SRC = 0x02`、`SEQ = 0x01`：

```text
DEMO_STOP:
A5 5A 02 00 01 01 00 BA

DEMO_HOME:
A5 5A 02 00 03 01 00 6C
```

### 4.6 DEMO_STATUS

`CTRL_SYS_RPT_DEMO_STATUS = 0x80`，payload 长度固定为 `16` bytes：

```c
typedef struct {
    uint32_t tick_ms;
    uint8_t state;
    uint8_t fault;
    uint8_t demo_id;
    uint8_t src_layer;
    uint8_t dst_layer;
    uint8_t variant;
    uint8_t step_index;
    uint8_t step_count;
    uint8_t active;
    uint8_t reserved[3];
} ctrl_demo_status_payload_t;
```

`DemoTask` 运行时会通过 telemetry 周期上报该状态。上位机可用 `step_index / step_count` 显示执行进度，用 `active` 判断当前是否正在执行 demo。
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

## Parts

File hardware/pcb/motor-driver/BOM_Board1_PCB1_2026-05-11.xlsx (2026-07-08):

No. | Quantity | Comment | Designator | Footprint | Value | Manufacturer Part | Manufacturer | Supplier Part | Supplier
1 | 2 | 220uF | C1,C2 | CAP-SMD_BD6.3-L6.6-W6.6-LS7.3-FD | 220uF | RV35V220M6X8 | JIERR(捷而瑞) | C48971006 | LCSC |  | 2
2 | 7 | 100nF | C3,C4,C8,C12,C16,C20,C24 | C0603 | 100nF | CL10B104KB8NNNC | SAMSUNG(三星) | C1591 | LCSC | 1
3 | 10 | 1uF | C5,C6,C10,C11,C14,C15,C18,C19,C22,C23 | C0603 | 1uF | CL10B105KB8NQNC | SAMSUNG(三星) | C5199872 | LCSC | 1
4 | 1 | 1000uF | C7 | CAP-SMD_BD10.0-L10.3-W10.3-LS11.0-FD | 1000uF | JVJ25V1000M10X12 | JIERR(捷而瑞) | C49256851 | LCSC |  | 2
5 | 5 | 10uF | C9,C13,C17,C21,C25 | C0603 | 10uF | CL10A106MA8NRNC | SAMSUNG(三星) | C96446 | LCSC | 1
6 | 10 | 100pF | C26,C27,C28,C29,C30,C31,C32,C33,C34,C35 | C0603 | 100pF | CL10C101JB8NNNC | SAMSUNG(三星) | C14858 | LCSC | 1
7 | 1 | HX 2.54-6P LT | CN1 | CONN-SMD_6P-P2.50_HX-2.54-6P-LT |  | HX 2.54-6P LT | hanxia(韩下) | C5142097 | LCSC |  | 2
8 | 1 | SS34 | D1 | SMA_L4.3-W2.6-LS5.0-FD |  | SS34 | R+O(宏嘉诚) | C7420365 | LCSC |  | 2
9 | 1 | SMBJ16CA | D2 | SMB_L4.6-W3.6-LS5.3-BI |  | SMBJ16CA | Littelfuse(美国力特) | C151255 | LCSC | 1
10 | 1 | DC-012A-20A | DC1 | DC-IN-TH_DC-012A-20A |  | DC-012A-20A | 韩国韩荣 | C136743 | LCSC |  | 2
11 | 5 | PZ254V-11-05P | H1,H2,H3,H4,H5 | HDR-TH_5P-P2.54-V-M |  | PZ254V-11-05P | XFCN(兴飞) | C492404 | LCSC | 1
12 | 2 | PZ254V-12-4P | H6,H7 | HDR-TH_4P-P2.54-V-M-R2-C2-S2.54 |  | PZ254V-12-4P | XFCN(兴飞) | C492419 | LCSC | 1
13 | 1 | 68uH | L1 | IND-SMD_L7.1-W6.6_H5.0 | 68uH | SMMS0650-680M | SXN(顺翔诺) | C2894721 | LCSC |  | 2
14 | 1 | GL0603UB01 | LED1 | LED0603-RD_BLUE |  | GL0603UB01 | Guiguang light(桂光光电) | C51933294 | LCSC | 1
15 | 1 | 2kΩ | R1 | R0603 | 2kΩ | 0603WAJ0202T5E | UNI-ROYAL(厚声) | C25590 | LCSC | 1
16 | 5 | 4.7kΩ | R2,R4,R6,R8,R10 | R0603 | 4.7kΩ | 0603WAJ0472T5E | UNI-ROYAL(厚声) | C25999 | LCSC | 1
17 | 1 | HX KCD1-2P-X | SW1 | SW-TH_L22.2-W15.0-P7.00_KCD1-2P-P |  | HX KCD1-2P-X | hanxia(韩下) | C6917320 | LCSC |  | 2
18 | 1 | XL1509-5.0E1 | U1 | SOIC-8_L5.0-W4.0-P1.27-LS6.0-BL |  | XL1509-5.0E1 | XLSEMI(芯龙) | C61063 | LCSC |  | 2
19 | 5 | MP6612D | U2,U5,U7,U9,U11 | TSSOP-20EP-6.6-6.6 |  |  |  |  |  |  | 2
20 | 4 | HX 2.54-6P WT | U3,U6,U8,U10 | CONN-SMD_6P-P2.50_HANXIA_HX-2.54-6P-WT |  | HX 2.54-6P WT | hanxia(韩下) | C5142102 | LCSC |  | 2
21 | 1 | KF301-5.0-2P | U4 | CONN-TH_P5.00_KF301-5.0-2P |  | KF301-5.0-2P | KEFA(科发) | C474881 | LCSC | 1

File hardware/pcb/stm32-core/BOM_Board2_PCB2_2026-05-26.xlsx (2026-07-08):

No. | Quantity | Comment | Designator | Footprint | Value | Manufacturer Part | Manufacturer | Supplier Part | Supplier
1 | 2 | 20pF | C1,C2 | C0603 | 20pF | CL10C200JB8NNNC | SAMSUNG(三星) | C1648 | LCSC | 1
2 | 11 | 100nF | C3,C4,C7,C9,C11,C14,C16,C18,C20,C24,C40 | C0603 | 100nF | CL10B104KB8NNNC | SAMSUNG(三星) | C1591 | LCSC | 1
3 | 8 | 1uF | C5,C6,C8,C10,C12,C15,C17,C19 | C0603 | 1uF | CL10A105KB8NNNC | SAMSUNG(三星) | C15849 | LCSC | 1
4 | 1 | 4.7uF | C13 | C0603 | 4.7uF | CL10A475KO8NNNC | SAMSUNG(三星) | C19666 | LCSC | 1
5 | 1 | ZMM5V6-M | D1 | LL-34_L3.5-W1.5-RD |  | ZMM5V6-M | ST(先科) | C8062 | LCSC | 1
6 | 3 | 2.54-1*4P母 | H1,H2,H3 | HDR-TH_4P-P2.54-V-F |  | 2.54-1*4P母 | BOOMELE(博穆精密) | C2718488 | LCSC | 1
7 | 2 | TS3425BA | KEY_NRST1,KEY_USER1 | SW-SMD_4P-L4.2-W3.2-P2.15-LS4.6-1 |  | TS3425BA | SHOU HAN(首韩) | C2681476 | LCSC | 1
8 | 2 | GL0603UG01 | LED_PWR1,LED_USER1 | LED0603-RD |  | GL0603UG01 | Guiguang light(桂光光电) | C51933293 | LCSC | 1
9 | 4 | 1kΩ | R1,R7,R8,R30 | R0603 | 1kΩ | 0603WAF1001T5E | UNI-ROYAL(厚声) | C21190 | LCSC | 1
10 | 1 | 1.5kΩ | R2 | R0603 | 1.5kΩ | 0603WAF1501T5E | UNI-ROYAL(厚声) | C22843 | LCSC | 1
11 | 2 | 5.1kΩ | R3,R4 | R0603 | 5.1kΩ | 0603WAF5101T5E | UNI-ROYAL(厚声) | C23186 | LCSC | 1
12 | 2 | 22Ω | R5,R6 | R0603 | 22Ω | 0603WAF220JT5E | UNI-ROYAL(厚声) | C23345 | LCSC | 1
13 | 1 | 30kΩ | R9 | R0603 | 30kΩ | 0603WAF3002T5E | UNI-ROYAL(厚声) | C22984 | LCSC |  | 2
14 | 1 | 10kΩ | R10 | R0603 | 10kΩ | 0603WAJ0103T5E | UNI-ROYAL(厚声) | C15401 | LCSC | 1
15 | 1 | STM32G474VCT6 | U1 | LQFP-100_L14.0-W14.0-P0.50-LS16.0-BL |  | STM32G474VCT6 | ST(意法半导体) | C730131 | LCSC |  | 2
16 | 1 | 2.54-2*15P | U2 | HDR-TH_30P-P2.54-V-F-R2-C15-S2.54 |  | 2.54-2*15P | BOOMELE(博穆精密) | C5337168 | LCSC | 1
17 | 2 | DS1021-1x2SF11-B | U3,U14 | HDR-TH_2P-P2.54-V-M |  | DS1021-1x2SF11-B | CONNFLY | C7430358 | LCSC | 1
18 | 1 | XC6220B331MR | U4 | SOT-23-5_L2.9-W1.6-P0.95-LS2.8-BR |  | XC6220B331MR | TECH PUBLIC(台舟) | C3040644 | LCSC |  | 2
19 | 5 | MTP125-1105S1 | U5,U6,U7,U8,U9 | HDR-TH_5P-P2.54-V-M |  | MTP125-1105S1 | MINTRON(明硕) | C358687 | LCSC | 1
20 | 2 | PH2.54-01-03PZD | U10,U11 | HDR-TH_3P-P2.54-V-M |  | PH2.54-01-03PZD | XUNPU(讯普) | C7501581 | LCSC | 1
21 | 1 | WAFER-GH1.25-4PWB | U12 | CONN-SMD_4P-P1.25_XUNPU_WAFER-GH1.25-4PWB |  | WAFER-GH1.25-4PWB | XUNPU(讯普) | C3029379 | LCSC | 1
22 | 1 | LMV321IDBVR | U13 | SOT-23-5_L3.0-W1.7-P0.95-LS2.8-BR |  | LMV321IDBVR | TI(德州仪器) | C7972 | LCSC |  | 2
23 | 3 | SN74LVC244ARWPR | U16,U17,U18 | X1-QFN-20_L3.3-W2.5-P0.40-TL-EP1.9 |  | SN74LVC244ARWPR | TI(德州仪器) | C2863409 | LCSC |  | 2
24 | 1 | TYPE-C 16PIN 2MD(073) | USB2 | USB-C-SMD_TYPE-C-6PIN-2MD-073 |  | TYPE-C 16PIN 2MD(073) | SHOU HAN(首韩) | C2765186 | LCSC | 1
25 | 1 | 12MHz | X2 | CRYSTAL-SMD_4P-L3.2-W2.5-BL | 12MHz | X322512MSB4SI | YXC(扬兴晶振) | C9002 | LCSC | 1

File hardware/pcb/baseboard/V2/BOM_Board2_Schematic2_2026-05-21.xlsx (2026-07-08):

No. | Quantity | Comment | Designator | Footprint | Value | Manufacturer Part | Manufacturer | Supplier Part | Supplier | 已有 | 买
1 | 24 | 100nF | C1,C4,C6,C9,C10,C11,C12,C13,C17,C18,C19,C20,C21,C22,C23,C26,C27,C28,C29,C30,C31,C33,C34,C35 | C0603_2 | 100nF | CGA0603X7R104K500JT | HRE(芯声) | C6119867 | LCSC | 1
2 | 1 | 22pF | C2 | C0603_2 | 22pF | CL10C220JB8NNNC | SAMSUNG(三星) | C1653 | LCSC | 1
3 | 2 | 10uF | C3,C7 | C0603_2 | 10uF | CL10A106KP8NNNC | SAMSUNG(三星) | C19702 | LCSC | 1
4 | 1 | 22uF | C5 | C0603_2 | 22uF | CL10A226MQ8NRNC | SAMSUNG(三星) | C59461 | LCSC | 1
5 | 2 | 4.7uF | C8,C14 | C0603_2 | 4.7uF | CGA0603X5R475K250JT | HRE(芯声) | C6119856 | LCSC | 1
6 | 2 | 10nF | C15,C37 | C0603_2 | 10nF | 0603B103K500NT | FH(风华) | C57112 | LCSC | 1
7 | 1 | 1nF | C16 | C0603_2 | 1nF | CL10B102KB8NNNC | SAMSUNG(三星) | C1588 | LCSC | 1
8 | 2 | 12pF | C24,C25 | C0402_2 | 12pF | CGA0402C0G120J500GT | HRE(芯声) | C45359894 | LCSC | 1
9 | 2 | 10uF | C32,C36 | C0603 | 10uF | CL10A106KP8NNNC | SAMSUNG(三星) | C19702 | LCSC | 1
10 | 1 | 100uF | C39 | CAP-TH_BD6.0-P2.50-D0.5-FD | 100uF | KM1E101M0611 | ROQANG(容强) | C2873969 | LCSC | 1
11 | 4 | PESD5V0S1BA | D1,D2,D3,D4 | SOD-323_L1.7-W1.3-LS2.5-BI |  | PESD5V0S1BA | TECH PUBLIC(台舟) | C2827694 | LCSC |  | 2
12 | 1 | AFE03-S39FMA-1H | FPC1 | FPC-SMD_P0.30-39P_FGS-XJ-H1.0 |  | AFE03-S39FMA-1H | JS(钜硕电子) | C262546 | LCSC | 1
13 | 4 | 125 X 300 | K1,K2,K3,K4 | 125 X 300 |  |  |  |  |  | 0
14 | 2 | 2.2uH | L1,L2 | IND-SMD_L2.5-W2.0_WPN252012H_2 | 2.2uH | WPN252012H2R2MT | Sunlord(顺络) | C98350 | LCSC | 1
15 | 1 | G2406S | L3 | SMD-24_L15.1-W7.1-P1.00-LS10.0-BL_2 |  | G2406S | CND-tek(磁联达) | C507595 | LCSC | 1
16 | 3 | CBM160808U121T | L4,L5,L6 | L0603_2 |  | CBM160808U121T | FH(风华) | C62708 | LCSC | 1
17 | 1 | 19-217/GHC-YR1S2/3T | LED1 | LED0603-RD_2 |  | 19-217/GHC-YR1S2/3T | EVERLIGHT(亿光) | C72043 | LCSC | 1
18 | 1 | 15kΩ | R1 | R0603_5 | 15kΩ | FRC0603F1502TS | FOJAN(富捷) | C2906995 | LCSC | 1
19 | 1 | 232kΩ | R2 | R0603_5 | 232kΩ | FRC0603F2323TS | FOJAN(富捷) | C3000719 | LCSC | 1
20 | 13 | 4.7kΩ | R3,R7,R8,R10,R11,R12,R13,R14,R15,R17,R19,R20,R47 | R0603_5 | 4.7kΩ | RC0603FR-074K7L | YAGEO(国巨) | C99782 | LCSC | 1
21 | 3 | 10kΩ | R4,R6,R28 | R0603_5 | 10kΩ | FRC0603F1002TS | FOJAN(富捷) | C2906982 | LCSC | 1
22 | 1 | 50kΩ | R5 | R0603_5 | 50kΩ | RT0603BRD0750KL | YAGEO(国巨) | C861451 | LCSC | 1
23 | 1 | 2.49kΩ | R9 | R0603_5 | 2.49kΩ | 0603WAF2491T5E | UNI-ROYAL(厚声) | C22908 | LCSC | 1
24 | 1 | 120Ω | R16 | R0603_5 | 120Ω | FRC0603F1200TS | FOJAN(富捷) | C2906988 | LCSC | 1
25 | 1 | 100Ω | R18 | R0603_5 | 100Ω | FRC0603F1502TS | FOJAN(富捷) |  | LCSC | 1
26 | 4 | 75Ω | R21,R22,R23,R24 | R0603_5 | 75Ω | 0603WAF750JT5E | UNI-ROYAL(厚声) | C4275 | LCSC | 1
27 | 14 | 22Ω | R25,R26,R27,R29,R30,R31,R32,R33,R34,R35,R36,R37,R38,R39 | R0402_8 | 22Ω | 0402WGF220JTCE | UNI-ROYAL(厚声) | C25092 | LCSC |  | 2
28 | 2 | 510Ω | R40,R43 | R0603_5 | 510Ω | 0603WAF5100T5E | UNI-ROYAL(厚声) | C23193 | LCSC | 1
29 | 1 | 10MΩ | R41 | R0603_5 | 10MΩ | 0603WAF1005T5E | UNI-ROYAL(厚声) | C7250 | LCSC |  | 2
30 | 1 | RC01812 | RJ1 | RJ45-TH_RC01812_2 |  | RC01812 | RCH(瑞川) | C708645 | LCSC |  | 2
31 | 1 | SY8113BADC | U1 | TSOT-23-6_L2.9-W1.6-P0.95-LS2.8-BR_1 |  | SY8113BADC | silergy(矽力杰) | C78989 | LCSC | 1
32 | 1 | TP5108E23E-18 | U2 | SOT-23-5_L3.0-W1.7-P0.95-LS2.8-BL_1 |  | TP5108E23E-18 | TECH PUBLIC(台舟) | C907845 | LCSC | 1
33 | 1 | RTL8211F-CG | U3 | WQFN-40_L5.0-W5.0-P0.4-BL-EP |  | RTL8211F-CG | REALTEK(瑞昱) | C187932 | LCSC | 1
34 | 1 | UGEPATAEYA | USB2 | USB-3.0-A-TH_HC |  | UGEPATAEYA | SAMZO(三佐) | C42371080 | LCSC | 1
35 | 1 | 25MHz | X1 | CRYSTAL-SMD_4P-L3.2-W2.5-BL | 25MHz | X322525MOB4SI | YXC(扬兴晶振) | C9006 | LCSC | 1

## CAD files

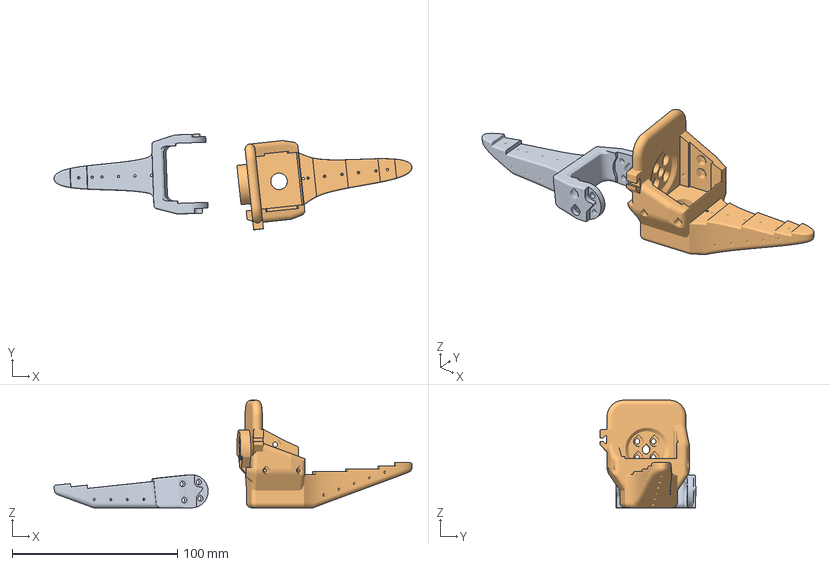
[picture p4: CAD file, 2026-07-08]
hardware/cad/arm/SO101/Follower_Specific/part10-11.3mf
216.9 x 58.1 x 65.2 mm
Moving_Jaw_SO101.step
Wrist_Roll_Follower_SO101.step

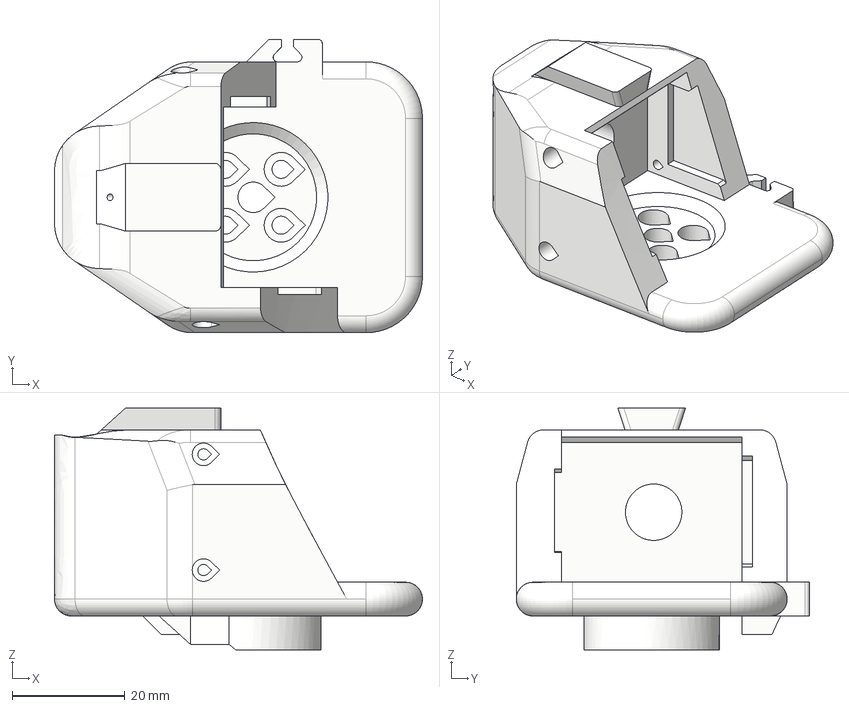
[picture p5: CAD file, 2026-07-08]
hardware/cad/arm/SO101/Leader_Specific/Wrist_Roll_SO101.step
65.2 x 52.0 x 42.9 mm
Wiring_holder v1
Wiring_holder v1 (1)

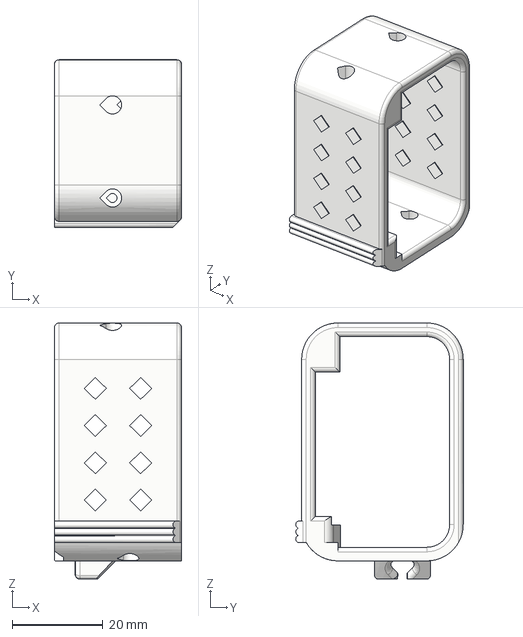
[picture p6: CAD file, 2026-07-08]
hardware/cad/arm/SO101/Motor_holder_SO101_Wrist.step
28.0 x 36.9 x 56.4 mm
Wiring_holder v1
Wiring_holder v1 (1)

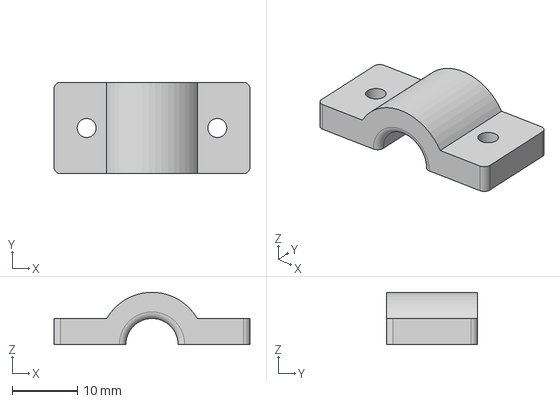
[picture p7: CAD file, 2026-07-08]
hardware/cad/chassis/wires_fixer_up.step
30.0 x 14.0 x 7.98 mm

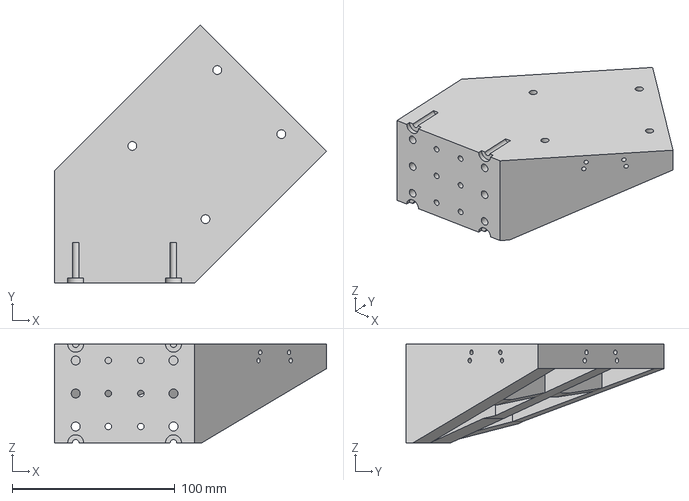
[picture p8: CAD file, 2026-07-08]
hardware/cad/lift/lift_platform_2.step
166.9 x 158.4 x 60.5 mm

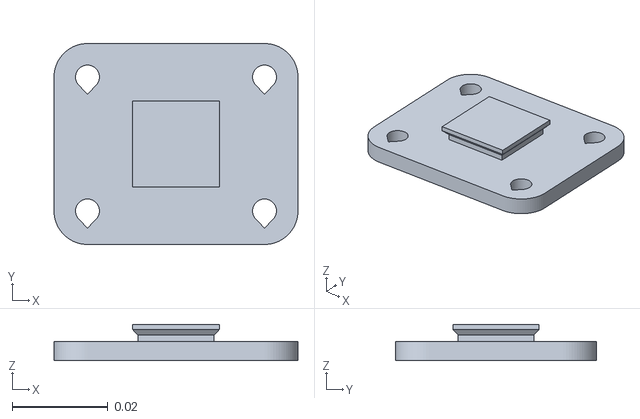
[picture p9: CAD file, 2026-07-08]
hardware/matlab/assets/waveshare_mounting_plate_so101_v2.stl
0.051 x 0.042 x 0.0076

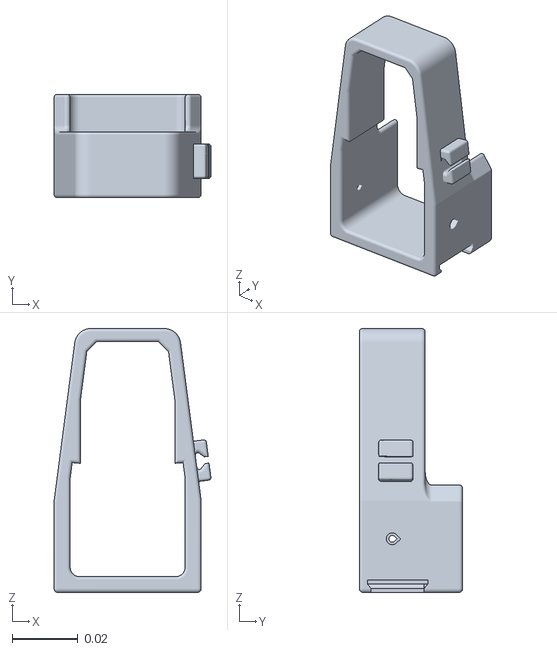
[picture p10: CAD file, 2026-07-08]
ros2/navigation/k1muse_description/meshes/so101/base_motor_holder_so101_v1.stl
0.0476 x 0.0314 x 0.0802

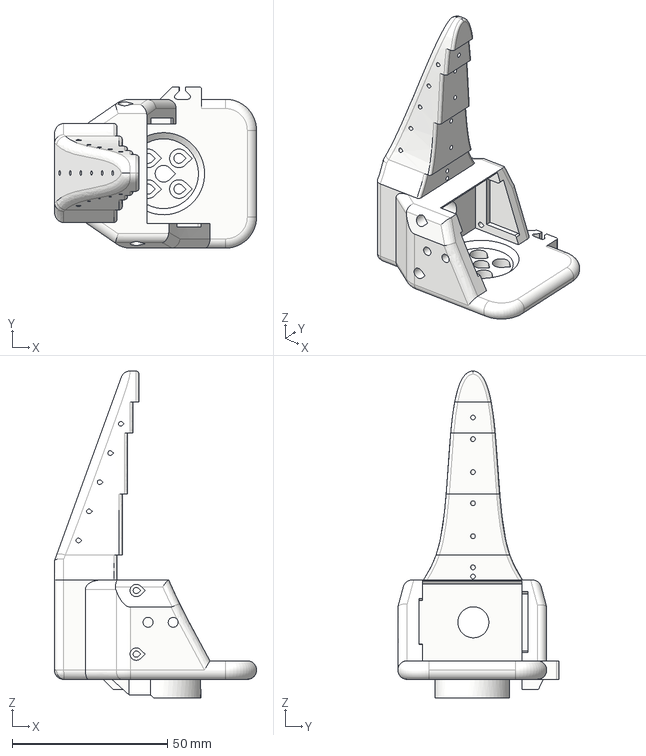
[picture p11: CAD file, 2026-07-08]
hardware/cad/arm/SO101/Follower_Specific/Wrist_Roll_Follower_SO101.step
65.2 x 52.0 x 105.4 mm
Wiring_holder v1
Wiring_holder v1 (1)

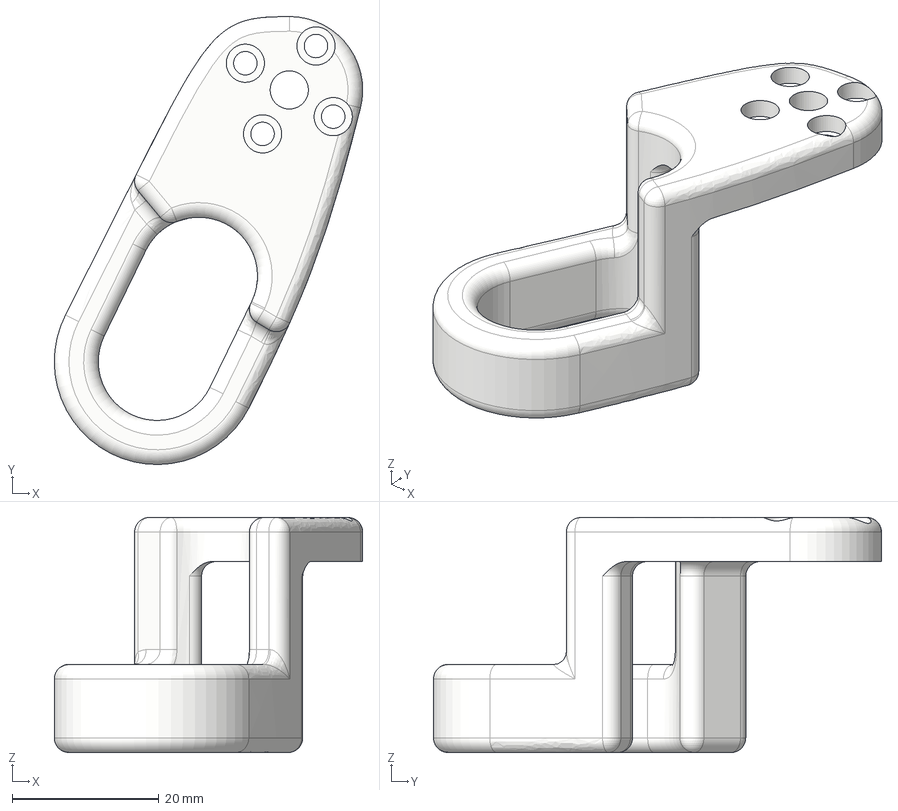
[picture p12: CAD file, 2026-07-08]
hardware/cad/arm/SO101/Leader_Specific/Trigger_SO101.step
42.0 x 61.0 x 32.0 mm

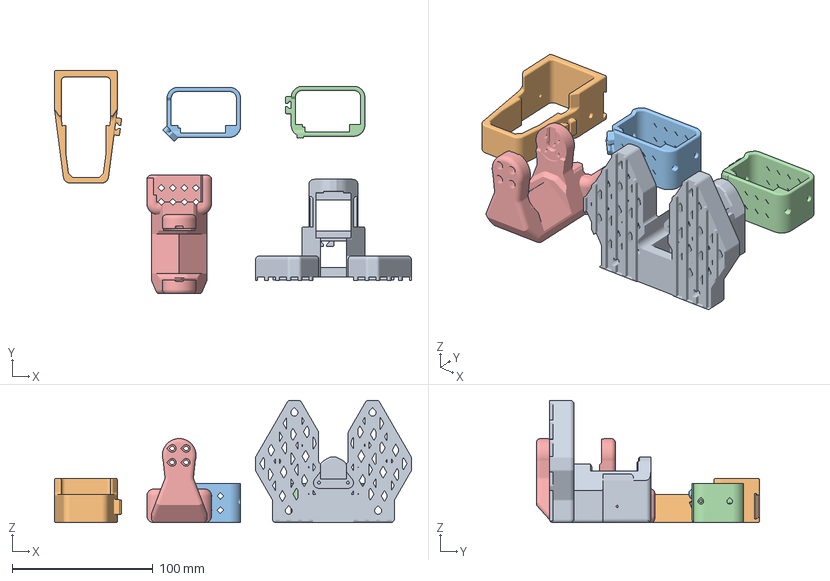
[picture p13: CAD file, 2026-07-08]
hardware/cad/arm/SO101/part1_5.3mf
253.7 x 158.7 x 87.0 mm
Base_SO101.step
Base_motor_holder_SO101.step
Motor_holder_SO101_Base.step
Motor_holder_SO101_Wrist.step
Rotation_Pitch_SO101.step

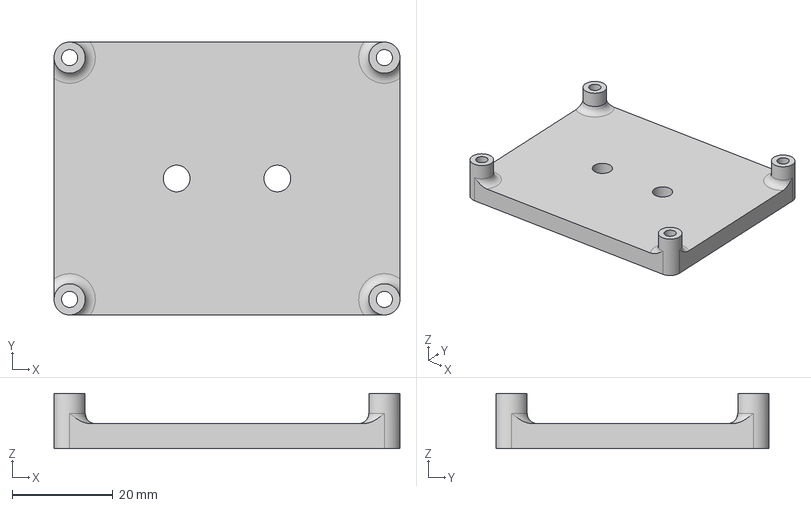
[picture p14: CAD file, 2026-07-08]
hardware/cad/chassis/STM32_down.step
68.7 x 54.2 x 11.0 mm

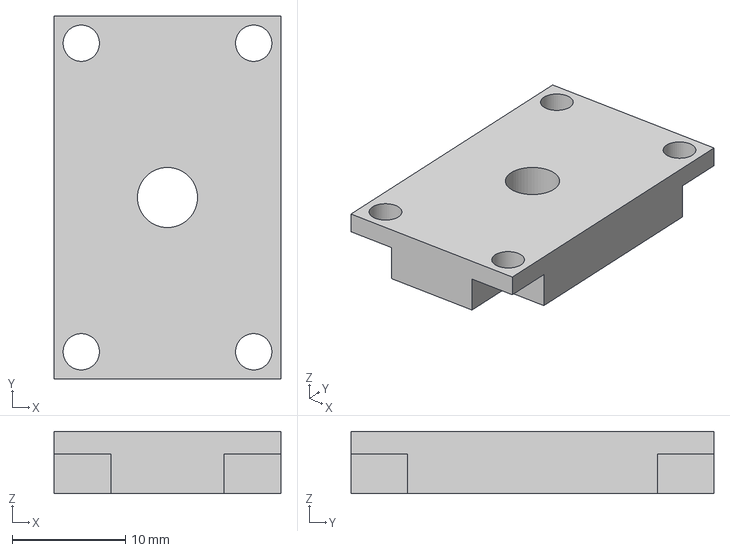
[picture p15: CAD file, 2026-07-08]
hardware/cad/mounts/gas_sensor_down.step
20.0 x 32.0 x 5.50 mm

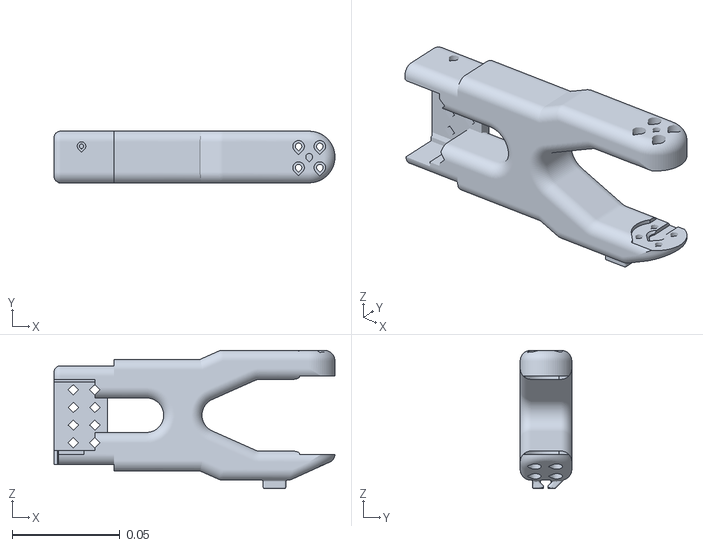
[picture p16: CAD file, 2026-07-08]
hardware/matlab/assets/under_arm_so101_v1.stl
0.131 x 0.024 x 0.0644

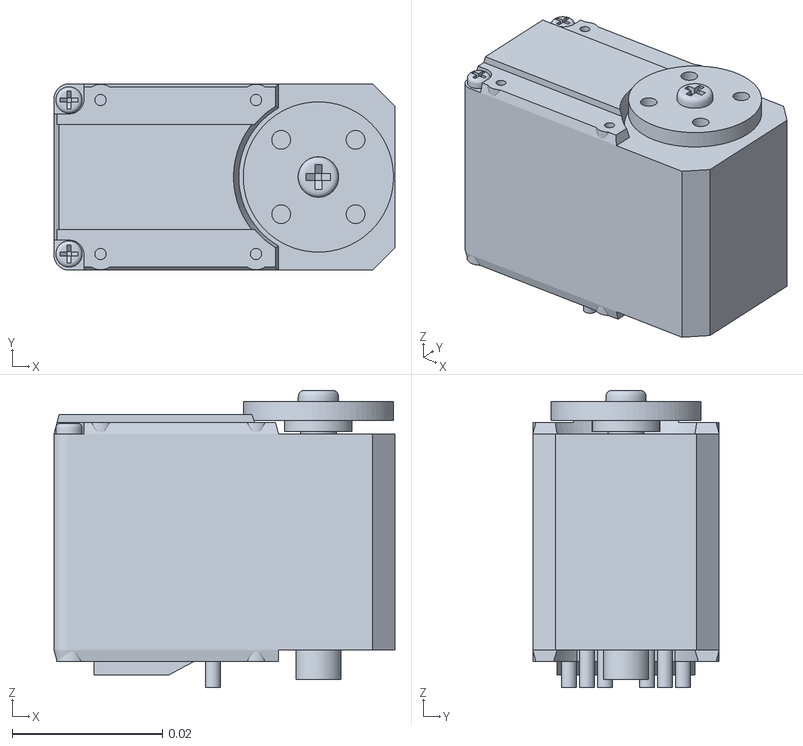
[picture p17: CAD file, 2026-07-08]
ros2/navigation/k1muse_description/meshes/so101/sts3215_03a_no_horn_v1.stl
0.0454 x 0.0248 x 0.0396

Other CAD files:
hardware/cad/mounts/usb3_0_wire_fixer.step
hardware/cad/arm/SO101/Follower_Specific/Moving_Jaw_SO101.step
hardware/cad/arm/SO101/Leader_Specific/Handle_SO101.step
hardware/cad/arm/SO101/Upper_arm_SO101.step
hardware/cad/arm/SO101/Base_SO101.step
hardware/cad/arm/SO101/Base_motor_holder_SO101.step
hardware/cad/arm/SO101/Motor_holder_SO101_Base.step
hardware/cad/arm/SO101/Rotation_Pitch_SO101.step
hardware/cad/arm/SO101/Seeedstudio_Mounting_Plate_SO101.step
hardware/cad/arm/SO101/Under_arm_SO101.step
hardware/cad/arm/SO101/WaveShare_Mounting_Plate_SO101.step
hardware/cad/arm/SO101/Wrist_Roll_Pitch_SO101.3mf
hardware/cad/arm/SO101/Wrist_Roll_Pitch_SO101.step
hardware/cad/arm/SO101/part6-9.3mf
hardware/cad/chassis/2motor_drive_down.3mf
hardware/cad/chassis/2motor_drive_down.step
hardware/cad/chassis/4motor_driver_down.3mf
hardware/cad/chassis/4motor_driver_down.step
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

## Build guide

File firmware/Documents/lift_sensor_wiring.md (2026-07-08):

# 升降三传感器接线

## 用途

升降机构目前使用三个位置传感器：

- `bottom`：底部传感器，用于原点/回零
- `middle`：中部传感器，用于后续中间位置参考
- `top`：顶部传感器，用于后续顶部位置参考或限位保护

三个传感器的 `VCC` 和 `GND` 已经共接，三个传感器各自单独引出 `D0` 信号线。

## STM32 引脚对应

| 传感器 | CubeMX Label | STM32 引脚 | GPIO 模式 | 当前软件用途 |
| --- | --- | --- | --- | --- |
| 底部 bottom | `LIFT_BOTTOM_SENSOR` | `PD14` | Input + Pull-up | 回零/home |
| 中部 middle | `LIFT_MIDDLE_SENSOR` | `PD8` | Input + Pull-up | 状态采样/诊断 |
| 顶部 top | `LIFT_TOP_SENSOR` | `PB13` | Input + Pull-up | 状态采样/诊断 |

## 杜邦线颜色记录

| 信号 | 杜邦线颜色 | 备注 |
| --- | --- | --- |
| 公共 VCC | 红色 | 三个传感器共用 |
| 公共 GND | 棕色 | 三个传感器共用 |
| bottom D | 白色 | 接 `PD14` |
| middle D | 灰色 | 接 `PD8` |
| top D | 紫色 | 接 `PB13` |

## 电平约定

当前 GPIO 使用 `GPIO_PULLUP`。按现有软件约定：

| 状态 | 电平 |
| --- | --- |
| 未触发/未遮挡 | `1` |
| 触发/遮挡 | `0` |

对应配置位于：

```c
#define LIFT_HOME_SENSOR_BLOCKED_LEVEL (0U)
#define LIFT_HOME_SENSOR_CLEAR_LEVEL   (1U)
```

## 注意事项

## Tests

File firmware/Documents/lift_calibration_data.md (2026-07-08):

# 升降机构标定数据

本文档记录升降机构的坐标定义、传感器边沿含义、已测量标定值，以及建议写入
`Application/Module/mdl_lift_config.h` 的配置值。

## 坐标定义

- 本文所有 `z` 均表示：从底部参考平面到升降装置最下方的距离。
- `z = 0 m` 表示升降装置最下方与底部参考平面重合，或软件定义的等效零点。
- `z` 正方向为升降向上。
- 传感器电平定义：
  - 未遮挡：`1`
  - 遮挡：`0`
- 边沿定义：
  - `falling_edge`：`1 -> 0`，进入遮挡区。
  - `rising_edge`：`0 -> 1`，离开遮挡区。

## 软件限位与物理限位

`LIFT_Z_MAX_M` 是正常运动命令的软件上限，不是机械硬限位，也不是 top 传感器触发点。

当前实测：

| 项目 | z / m | 说明 |
|---|---:|---|
| 正常软件上限 | `0.500` | 当前 `LIFT_Z_MAX_M`，用于限制普通 `MOVE_Z` 目标 |
| top 上行触发点 | `0.493` | 向上运动进入 top 传感器遮挡区的位置 |
| 机械顶部余量 | 约 `0.010` | top 触发后到机械顶端仍有约 1 cm 余量 |

工程建议：

- `LIFT_Z_MAX_M` 作为正常工作区软件上限，由软件目标范围约束。
- top 传感器只作为位置参考点，用于修正编码器累计误差，不承担限位或停车职责。
- 如果未来需要扩大正常工作区，应先确认机械余量、制动距离和负载条件，再调整 `LIFT_Z_MAX_M`。

## 基础机械参数

| 数据项 | 当前配置 | 当前值 | 说明 |
|---|---|---:|---|
| 未归零默认值 | `LIFT_Z_UNHOMED_DEFAULT_M` | `0.000f` | home 完成前使用的默认 z，不代表 HOME 完成位置 |
| 最小允许 z | `LIFT_Z_MIN_M` | `0.000f` | 正常运动下限 |
| 最大允许 z | `LIFT_Z_MAX_M` | `0.500f` | 正常运动软件上限 |
| 每圈理论行程 | `LIFT_TRAVEL_PER_ROUND_M` | `0.040f` | 当前按 40 mm/round 计算 |
| 行程修正系数 | `LIFT_TRAVEL_CALIBRATION_SCALE` | `1.000f` | 后续可用于修正累计比例误差 |
| 编码器每圈计数 | `LIFT_ENCODER_COUNT_PER_ROUND` | `1584U` | 当前编码器换算基准 |

## Bottom Home 传感器

bottom 传感器用于上电 home。它位于软件零点上方，因此 home 完成后不是把 z 置为 0，而是按实际触发边沿写入对应 z 值。

| 测量项 | 运动方向 | 电平边沿 | 配置项 | 实测值 / m | 建议配置 |
|---|---|---|---|---:|---|
| bottom 离开遮挡区 | 向上 | rising | `LIFT_HOME_RISING_Z_M` | `0.080` | `0.080f` |
| bottom 进入遮挡区 | 向下 | falling | `LIFT_HOME_FALLING_Z_M` | `0.077` | `0.077f` |

## Middle 参考传感器

middle 传感器有一段遮挡区，上下两个方向都会经过进入/离开遮挡区的边沿。该传感器适合作为中段位置参考，用于修正编码器累计误差。

| 测量项 | 运动方向 | 物理触发说明 | 电平边沿 | 配置项 | 最终值 / m | 建议配置 |
|---|---|---|---|---|---:|---|
| middle 进入遮挡区 | 向上 | 升降挡片上边沿触发 | falling | `LIFT_MIDDLE_UP_FALLING_Z_M` | `0.246` | `0.246f` |
| middle 离开遮挡区 | 向上 | 升降挡片下边沿释放 | rising | `LIFT_MIDDLE_UP_RISING_Z_M` | `0.341` | `0.341f` |
| middle 进入遮挡区 | 向下 | 升降挡片下边沿触发 | falling | `LIFT_MIDDLE_DOWN_FALLING_Z_M` | `0.337` | `0.337f` |
| middle 离开遮挡区 | 向下 | 升降挡片上边沿释放 | rising | `LIFT_MIDDLE_DOWN_RISING_Z_M` | `0.246` | `0.246f` |

说明：

- 向上进入遮挡区和向下离开遮挡区都在约 `0.246 m`，对应遮挡区下边界附近。
- 向上离开遮挡区和向下进入遮挡区分别为 `0.341 m` 与 `0.337 m`，两者相差约 `4 mm`，可视为传感器迟滞、机械间隙、制动和人工读数误差的综合结果。
- 若后续用于在线校准，建议先保持 `LIFT_SENSOR_REF_MAX_ERROR_M = 0.010f`，确认稳定后再收紧到 `0.003f ~ 0.005f`。

## Top 参考传感器

top 传感器只用于位置校准。当前实际结构中，可靠使用的是上行进入遮挡区的触发点和下行离开遮挡区的释放点；真正的限位由 `LIFT_Z_MIN_M` / `LIFT_Z_MAX_M` 软件目标范围负责。

| 测量项 | 运动方向 | 物理触发说明 | 电平边沿 | 配置项 | 最终值 / m | 建议配置 |
|---|---|---|---|---|---:|---|
| top 进入遮挡区 | 向上 | 升降挡片上边沿触发 | falling | `LIFT_TOP_UP_FALLING_Z_M` | `0.493` | `0.493f` |
| top 离开遮挡区 | 向下 | 升降挡片上边沿释放 | rising | `LIFT_TOP_DOWN_RISING_Z_M` | `0.490` | `0.490f` |

## 建议回填配置

```c
#define LIFT_Z_MAX_M (0.50f)

#define LIFT_HOME_RISING_Z_M (0.080f)
#define LIFT_HOME_FALLING_Z_M (0.077f)

#define LIFT_MIDDLE_UP_RISING_Z_M (0.341f)
#define LIFT_MIDDLE_UP_FALLING_Z_M (0.246f)
#define LIFT_MIDDLE_DOWN_RISING_Z_M (0.246f)
#define LIFT_MIDDLE_DOWN_FALLING_Z_M (0.337f)

#define LIFT_TOP_UP_FALLING_Z_M (0.493f)
#define LIFT_TOP_DOWN_RISING_Z_M (0.490f)
```

说明：

- `LIFT_Z_MAX_M = 0.50f` 保留为正常软件上限。
- `LIFT_TOP_UP_FALLING_Z_M = 0.493f` 记录 top 上行位置校准点。
- top 参考点和软件上限相互独立，调整 `LIFT_Z_MAX_M` 不应改变 top 传感器标定值。

## 测试检查项

回填配置并烧录后，建议按以下顺序检查：

1. 上电 home，确认最终停在 bottom home 对应位置，`is_homed = 1`。
2. 小范围 `MOVE_Z`，确认 `current_z` 与尺子读数趋势一致。
3. 低速穿过 middle，确认 `last_ref_sensor = 1`，`last_ref_error` 小于 `LIFT_SENSOR_REF_MAX_ERROR_M`。
4. 慢速靠近 top，确认 top 触发后仅更新参考校准状态，不触发保护或停车。
5. 多次往返后观察 `current_z` 是否有明显累计漂移，必要时再调整 `LIFT_TRAVEL_CALIBRATION_SCALE`。

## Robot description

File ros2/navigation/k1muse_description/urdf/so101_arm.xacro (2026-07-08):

<?xml version="1.0"?>
<robot xmlns:xacro="http://www.ros.org/wiki/xacro">
  <xacro:macro name="so101_arm" params="prefix parent *origin">
    <xacro:property name="so101_mesh_dir" value="package://k1muse_description/meshes/so101"/>

    <material name="so101_3d_printed">
      <color rgba="1.0 0.82 0.12 1.0"/>
    </material>
    <material name="so101_sts3215">
      <color rgba="0.1 0.1 0.1 1.0"/>
    </material>

    <joint name="${prefix}mount_joint" type="fixed">
      <parent link="${parent}"/>
      <child link="${prefix}base_link"/>
      <xacro:insert_block name="origin"/>
    </joint>

    <link name="${prefix}base_link">
      <visual>
        <origin xyz="-0.00636471 -9.94414e-05 -0.0024" rpy="1.5708 -1.67685e-15 1.5708"/>
        <geometry><mesh filename="${so101_mesh_dir}/base_motor_holder_so101_v1.stl"/></geometry>
        <material name="so101_3d_printed"/>
      </visual>
      <visual>
        <origin xyz="-0.00636471 -8.97657e-09 -0.0024" rpy="1.5708 -2.78073e-29 1.5708"/>
        <geometry><mesh filename="${so101_mesh_dir}/base_so101_v2.stl"/></geometry>
        <material name="so101_3d_printed"/>
      </visual>
      <visual>
        <origin xyz="0.0263353 -8.97657e-09 0.0437" rpy="-8.21148e-16 7.84513e-18 1.249e-15"/>
        <geometry><mesh filename="${so101_mesh_dir}/sts3215_03a_v1.stl"/></geometry>
        <material name="so101_sts3215"/>
      </visual>
      <visual>
        <origin xyz="-0.0309827 -0.000199441 0.0474" rpy="1.5708 -1.35493e-14 1.5708"/>
        <geometry><mesh filename="${so101_mesh_dir}/waveshare_mounting_plate_so101_v2.stl"/></geometry>
        <material name="so101_3d_printed"/>
      </visual>
    </link>

    <link name="${prefix}shoulder_link">
      <visual>
        <origin xyz="-0.0303992 0.000422241 -0.0417" rpy="1.5708 1.5708 0"/>
        <geometry><mesh filename="${so101_mesh_dir}/sts3215_03a_v1.stl"/></geometry>
        <material name="so101_sts3215"/>
      </visual>
      <visual>
        <origin xyz="-0.0675992 -0.000177759 0.0158499" rpy="1.5708 -1.5708 0"/>
        <geometry><mesh filename="${so101_mesh_dir}/motor_holder_so101_base_v1.stl"/></geometry>
        <material name="so101_3d_printed"/>
      </visual>
      <visual>
        <origin xyz="0.0122008 2.22413e-05 0.0464" rpy="-1.5708 2.35221e-33 0"/>
        <geometry><mesh filename="${so101_mesh_dir}/rotation_pitch_so101_v1.stl"/></geometry>
        <material name="so101_3d_printed"/>
      </visual>
    </link>

    <link name="${prefix}upper_arm_link">
      <visual>
        <origin xyz="-0.11257 -0.0155 0.0187" rpy="-3.14159 -5.27356e-16 -1.5708"/>
        <geometry><mesh filename="${so101_mesh_dir}/sts3215_03a_v1.stl"/></geometry>
        <material name="so101_sts3215"/>
      </visual>
      <visual>
        <origin xyz="-0.065085 0.012 0.0182" rpy="3.14159 0 0"/>
        <geometry><mesh filename="${so101_mesh_dir}/upper_arm_so101_v1.stl"/></geometry>
        <material name="so101_3d_printed"/>
      </visual>
    </link>

    <link name="${prefix}lower_arm_link">
      <visual>
        <origin xyz="-0.0648499 -0.032 0.0182" rpy="3.14159 0 0"/>
        <geometry><mesh filename="${so101_mesh_dir}/under_arm_so101_v1.stl"/></geometry>
        <material name="so101_3d_printed"/>
      </visual>
      <visual>
        <origin xyz="-0.0648499 -0.032 0.018" rpy="-3.14159 -2.55351e-15 0"/>
        <geometry><mesh filename="${so101_mesh_dir}/motor_holder_so101_wrist_v1.stl"/></geometry>
        <material name="so101_3d_printed"/>
      </visual>
      <visual>
        <origin xyz="-0.1224 0.0052 0.0187" rpy="-3.14159 0 -3.14159"/>
        <geometry><mesh filename="${so101_mesh_dir}/sts3215_03a_v1.stl"/></geometry>
        <material name="so101_sts3215"/>
      </visual>
    </link>

    <link name="${prefix}wrist_link">
      <visual>
        <origin xyz="8.32667e-17 -0.0424 0.0306" rpy="1.5708 1.5708 0"/>
        <geometry><mesh filename="${so101_mesh_dir}/sts3215_03a_no_horn_v1.stl"/></geometry>
        <material name="so101_sts3215"/>
      </visual>
      <visual>
        <origin xyz="0 -0.028 0.0181" rpy="-1.5708 -1.5708 0"/>
        <geometry><mesh filename="${so101_mesh_dir}/wrist_roll_pitch_so101_v2.stl"/></geometry>
        <material name="so101_3d_printed"/>
      </visual>
    </link>

    <link name="${prefix}gripper_link">
      <visual>
        <origin xyz="0.0077 0.0001 -0.0234" rpy="-1.5708 -5.19179e-17 -1.66533e-16"/>
        <geometry><mesh filename="${so101_mesh_dir}/sts3215_03a_v1.stl"/></geometry>
        <material name="so101_sts3215"/>
      </visual>
      <visual>
        <origin xyz="8.32667e-17 -0.000218214 0.000949706" rpy="-3.14159 -5.55112e-17 0"/>
        <geometry><mesh filename="${so101_mesh_dir}/wrist_roll_follower_so101_v1.stl"/></geometry>
        <material name="so101_3d_printed"/>
      </visual>
    </link>

    <link name="${prefix}tool0"/>

    <link name="${prefix}moving_jaw_link">
      <visual>
        <origin xyz="-5.55112e-17 -5.55112e-17 0.0189" rpy="0 0 0"/>
        <geometry><mesh filename="${so101_mesh_dir}/moving_jaw_so101_v1.stl"/></geometry>
        <material name="so101_3d_printed"/>
      </visual>
    </link>

    <joint name="${prefix}shoulder_pan" type="revolute">
      <origin xyz="0.0388353 -8.97657e-09 0.0624" rpy="3.14159 4.18253e-17 -3.14159"/>
      <parent link="${prefix}base_link"/>
      <child link="${prefix}shoulder_link"/>
      <axis xyz="0 0 1"/>
      <limit effort="10" velocity="10" lower="-1.78708768" upper="2.00031114"/>
    </joint>

    <joint name="${prefix}shoulder_lift" type="revolute">
      <origin xyz="-0.0303992 -0.0182778 -0.0542" rpy="-1.5708 -1.5708 0"/>
      <parent link="${prefix}shoulder_link"/>
      <child link="${prefix}upper_arm_link"/>
      <axis xyz="0 0 1"/>
      <limit effort="10" velocity="10" lower="-1.76561201" upper="1.67357314"/>
    </joint>

    <joint name="${prefix}elbow_flex" type="revolute">
      <origin xyz="-0.11257 -0.028 1.73763e-16" rpy="-3.63608e-16 8.74301e-16 1.5708"/>
      <parent link="${prefix}upper_arm_link"/>
      <child link="${prefix}lower_arm_link"/>
      <axis xyz="0 0 1"/>
      <limit effort="10" velocity="10" lower="-1.64442742" upper="1.48335946"/>
    </joint>

    <joint name="${prefix}wrist_flex" type="revolute">
      <origin xyz="-0.1349 0.0052 3.62355e-17" rpy="4.02456e-15 8.67362e-16 -1.5708"/>
      <parent link="${prefix}lower_arm_link"/>
      <child link="${prefix}wrist_link"/>
      <axis xyz="0 0 1"/>
      <limit effort="10" velocity="10" lower="-1.64749539" upper="1.63522363"/>
    </joint>

    <joint name="${prefix}wrist_roll" type="revolute">
      <origin xyz="5.55112e-17 -0.0611 0.0181" rpy="1.5708 0.0486795 3.14159"/>
      <parent link="${prefix}wrist_link"/>
      <child link="${prefix}gripper_link"/>
      <axis xyz="0 0 1"/>
      <limit effort="10" velocity="10" lower="-2.63691306" upper="2.62770915"/>
    </joint>

    <joint name="${prefix}tool0_fixed" type="fixed">
      <origin xyz="0 0 -0.0981274" rpy="0 3.14159 0"/>
      <parent link="${prefix}gripper_link"/>
      <child link="${prefix}tool0"/>
    </joint>

    <joint name="${prefix}gripper" type="revolute">
      <origin xyz="0.0202 0.0188 -0.0234" rpy="1.5708 -5.24284e-08 -1.41553e-15"/>
      <parent link="${prefix}gripper_link"/>
      <child link="${prefix}moving_jaw_link"/>
      <axis xyz="0 0 1"/>
      <limit effort="10" velocity="10" lower="-0.167203918" upper="1.88833046"/>
    </joint>
  </xacro:macro>
</robot>

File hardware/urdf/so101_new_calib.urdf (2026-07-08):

<?xml version="1.0" encoding="utf-8"?>
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
<robot name="so101_new_calib">

  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
  <link name="base_link">
    <inertial>
      <origin xyz="0.0137179 -5.19711e-05 0.0334843" rpy="0 0 0"/>
      <mass value="0.147"/>
      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
    </inertial>
    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
  </link>

  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
  <link name="shoulder_link">
    <inertial>
      <origin xyz="-0.0307604 -1.66727e-05 -0.0252713" rpy="0 0 0"/>
      <mass value="0.100006"/>
      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
    </inertial>
    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
  </link>

  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
  <link name="upper_arm_link">
    <inertial>
      <origin xyz="-0.0898471 -0.00838224 0.0184089" rpy="0 0 0"/>
      <mass value="0.103"/>
      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
    </inertial>
    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
  </link>

  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
  <link name="lower_arm_link">
    <inertial>
      <origin xyz="-0.0980701 0.00324376 0.0182831" rpy="0 0 0"/>
      <mass value="0.104"/>
      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
    </inertial>
    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
  </link>

  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
  <link name="wrist_link">
    <inertial>
      <origin xyz="-0.000103312 -0.0386143 0.0281156" rpy="0 0 0"/>
      <mass value="0.079"/>
      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
    </inertial>
    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
  </link>

  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
  <link name="gripper_link">
    <inertial>
      <origin xyz="0.000213627 0.000245138 -0.025187" rpy="0 0 0"/>
      <mass value="0.087"/>
      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
    </inertial>
    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
  </link>

  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
  <link name="gripper_frame_link">
    <origin xyz="0 0 0" rpy="0 -0 0"/>
    <inertial>
      <origin xyz="0 0 0" rpy="0 0 0"/>
      <mass value="1e-9"/>
      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
    </inertial>
  </link>

  <joint name="gripper_frame_joint" type="fixed">
    <origin xyz="-0.0079 -0.000218121 -0.0981274" rpy="0 3.14159 0"/>
    <parent link="gripper_link"/>
    <child link="gripper_frame_link"/>
    <axis xyz="0 0 0"/>
  </joint>

  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
  <link name="moving_jaw_so101_v1_link">
    <inertial>
      <origin xyz="-0.00157495 -0.0300244 0.0192755" rpy="0 0 0"/>
      <mass value="0.012"/>
      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
    </inertial>
    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
  </link>

  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
  <joint name="gripper" type="revolute">
    <origin xyz="0.0202 0.0188 -0.0234" rpy="1.5708 -5.24284e-08 -1.41553e-15"/>
    <parent link="gripper_link"/>
    <child link="moving_jaw_so101_v1_link"/>
    <axis xyz="0 0 1"/>
    <limit effort="10" velocity="10" lower="-0.174533" upper="1.74533"/>
  </joint>

  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
  <joint name="wrist_roll" type="revolute">
    <origin xyz="5.55112e-17 -0.0611 0.0181" rpy="1.5708 0.0486795 3.14159"/>
    <parent link="wrist_link"/>
    <child link="gripper_link"/>
    <axis xyz="0 0 1"/>
    <limit effort="10" velocity="10" lower="-2.74385" upper="2.84121"/>
  </joint>

  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
  <joint name="wrist_flex" type="revolute">
    <origin xyz="-0.1349 0.0052 3.62355e-17" rpy="4.02456e-15 8.67362e-16 -1.5708"/>
    <parent link="lower_arm_link"/>
    <child link="wrist_link"/>
    <axis xyz="0 0 1"/>
    <limit effort="10" velocity="10" lower="-1.65806" upper="1.65806"/>
  </joint>

  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
  <joint name="elbow_flex" type="revolute">
    <origin xyz="-0.11257 -0.028 1.73763e-16" rpy="-3.63608e-16 8.74301e-16 1.5708"/>
    <parent link="upper_arm_link"/>
    <child link="lower_arm_link"/>
    <axis xyz="0 0 1"/>
    <limit effort="10" velocity="10" lower="-1.69" upper="1.69"/>
  </joint>

  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
  <joint name="shoulder_lift" type="revolute">
    <origin xyz="-0.0303992 -0.0182778 -0.0542" rpy="-1.5708 -1.5708 0"/>
    <parent link="shoulder_link"/>
    <child link="upper_arm_link"/>
    <axis xyz="0 0 1"/>
    <limit effort="10" velocity="10" lower="-1.74533" upper="1.74533"/>
  </joint>

  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
  <joint name="shoulder_pan" type="revolute">
    <origin xyz="0.0388353 -8.97657e-09 0.0624" rpy="3.14159 4.18253e-17 -3.14159"/>
    <parent link="base_link"/>
    <child link="shoulder_link"/>
    <axis xyz="0 0 1"/>
    <limit effort="10" velocity="10" lower="-1.91986" upper="1.91986"/>
  </joint>

  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 

</robot>

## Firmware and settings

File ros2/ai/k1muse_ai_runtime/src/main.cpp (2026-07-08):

#include <memory>

#include <rclcpp/rclcpp.hpp>
#include <rclcpp/executors/multi_threaded_executor.hpp>

#include "k1muse_ai_runtime/ai_runtime_node.hpp"

int main(int argc, char ** argv)
{
  rclcpp::init(argc, argv);
  auto node = std::make_shared<k1muse_ai_runtime::AiRuntimeNode>();
  rclcpp::executors::MultiThreadedExecutor executor;
  executor.add_node(node->get_node_base_interface());
  executor.spin();
  rclcpp::shutdown();
  return 0;
}

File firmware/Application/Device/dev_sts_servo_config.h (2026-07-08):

#ifndef _DEV_STS_SERVO_CONFIG_H_
#define _DEV_STS_SERVO_CONFIG_H_

/* Protocol */
#define STS_SERVO_HEADER_1 (0xFFU)
#define STS_SERVO_HEADER_2 (0xFFU)
#define STS_SERVO_BROADCAST_ID (0xFEU)
#define STS_SERVO_MAX_ID (0xFDU)

/* Instructions */
#define STS_SERVO_INST_PING (0x01U)
#define STS_SERVO_INST_READ (0x02U)
#define STS_SERVO_INST_WRITE (0x03U)
#define STS_SERVO_INST_REG_WRITE (0x04U)
#define STS_SERVO_INST_ACTION (0x05U)
#define STS_SERVO_INST_RESET (0x06U)
#define STS_SERVO_INST_SYNC_READ (0x82U)
#define STS_SERVO_INST_SYNC_WRITE (0x83U)

/* Packet and queue sizing */
#define STS_SERVO_PACKET_OVERHEAD (6U)
#define STS_SERVO_MAX_PARAM_LEN (240U)
#define STS_SERVO_TX_BUF_SIZE (256U)
#define STS_SERVO_RX_TMP_BUF_SIZE (32U)
#define STS_SERVO_CMD_QUEUE_SIZE (4U)
#define STS_SERVO_RSP_QUEUE_SIZE (12U)

/* Timing */
#define STS_SERVO_DEFAULT_TIMEOUT_MS (20U)

/* Fault flags */
#define STS_SERVO_FAULT_NONE (0x00000000UL)
#define STS_SERVO_FAULT_OVER_TEMP (0x00000001UL)
#define STS_SERVO_FAULT_UNDER_VOLTAGE (0x00000002UL)
#define STS_SERVO_FAULT_OVER_VOLTAGE (0x00000004UL)
#define STS_SERVO_FAULT_OVER_LOAD (0x00000008UL)
#define STS_SERVO_FAULT_OVER_CURRENT (0x00000010UL)
#define STS_SERVO_FAULT_POSITION_ERROR (0x00000020UL)
#define STS_SERVO_FAULT_BUS_TIMEOUT (0x00000040UL)
#define STS_SERVO_FAULT_STATUS_ERROR (0x00000080UL)

/* Protection decision is confirmed by the task layer to avoid transient alarms
 * directly cutting torque during command execution or commissioning.
 */
#define STS_SERVO_PROTECT_DISABLE_TORQUE_FAULTS (STS_SERVO_FAULT_NONE)

/* Memory table addresses for magnetic encoder STS servos. */
#define STS_SERVO_ADDR_ID (0x05U)
#define STS_SERVO_ADDR_BAUDRATE (0x06U)
#define STS_SERVO_ADDR_RETURN_DELAY (0x07U)
#define STS_SERVO_ADDR_RESPONSE_LEVEL (0x08U)

#define STS_SERVO_ADDR_MIN_POSITION (0x09U)
#define STS_SERVO_ADDR_MAX_POSITION (0x0BU)
#define STS_SERVO_ADDR_MAX_TEMPERATURE (0x0DU)
#define STS_SERVO_ADDR_MAX_VOLTAGE (0x0EU)
#define STS_SERVO_ADDR_MIN_VOLTAGE (0x0FU)
#define STS_SERVO_ADDR_MAX_TORQUE (0x10U)

#define STS_SERVO_ADDR_MODE (0x21U)
#define STS_SERVO_ADDR_TORQUE_ENABLE (0x28U)
#define STS_SERVO_ADDR_ACC (0x29U)
#define STS_SERVO_ADDR_TARGET_POSITION (0x2AU)
#define STS_SERVO_ADDR_RUNNING_TIME (0x2CU)
#define STS_SERVO_ADDR_RUNNING_SPEED (0x2EU)
#define STS_SERVO_ADDR_TORQUE_LIMIT (0x30U)

#define STS_SERVO_ADDR_CURRENT_POSITION (0x38U)
#define STS_SERVO_ADDR_CURRENT_SPEED (0x3AU)
#define STS_SERVO_ADDR_CURRENT_LOAD (0x3CU)
#define STS_SERVO_ADDR_CURRENT_VOLTAGE (0x3EU)
#define STS_SERVO_ADDR_CURRENT_TEMP (0x3FU)
#define STS_SERVO_ADDR_STATUS (0x41U)
#define STS_SERVO_ADDR_MOVING (0x42U)
#define STS_SERVO_ADDR_CURRENT_CURRENT (0x45U)

/* Common values */
#define STS_SERVO_MODE_POSITION (0U)
#define STS_SERVO_TORQUE_DISABLE (0U)
#define STS_SERVO_TORQUE_ENABLE (1U)
#define STS_SERVO_TORQUE_DAMPING (2U)
#define STS_SERVO_TORQUE_CALIBRATE (128U)

/* Default device parameters */
#define STS_SERVO_POSITION_MIN_DEFAULT (0)
#define STS_SERVO_POSITION_MAX_DEFAULT (4095)
#define STS_SERVO_POSITION_ZERO_DEFAULT (2048)
#define STS_SERVO_POSITION_PER_RAD_DEFAULT (651.8986206f)
#define STS_SERVO_SPEED_DEFAULT (1200U)
#define STS_SERVO_ACC_DEFAULT (50U)

/* Conservative protection defaults.
 * Voltage uses the STS 0.1 V unit, temperature uses degrees Celsius.
 */
#define STS_SERVO_MAX_TEMPERATURE_DEFAULT (65U)
#define STS_SERVO_MIN_VOLTAGE_DEFAULT (60U)
#define STS_SERVO_MAX_VOLTAGE_DEFAULT (84U)
#define STS_SERVO_MAX_LOAD_DEFAULT (800U)
#define STS_SERVO_MAX_CURRENT_DEFAULT (1500U)
#define STS_SERVO_MAX_POSITION_ERROR_DEFAULT (300U)

#endif /* _DEV_STS_SERVO_CONFIG_H_ */

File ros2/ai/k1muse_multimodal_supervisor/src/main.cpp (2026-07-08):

#include <memory>

#include <rclcpp/rclcpp.hpp>

#include "k1muse_multimodal_supervisor/multimodal_supervisor_node.hpp"

int main(int argc, char** argv) {
  rclcpp::init(argc, argv);
  auto node =
      std::make_shared<k1muse_multimodal_supervisor::MultimodalSupervisorNode>();
  rclcpp::spin(node->get_node_base_interface());
  rclcpp::shutdown();
  return 0;
}

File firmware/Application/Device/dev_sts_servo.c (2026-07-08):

#include "dev_sts_servo.h"

#define STS_SERVO_MIN_PACKET_LEN (6U)
#define STS_SERVO_STATUS_READ_ADDR STS_SERVO_ADDR_CURRENT_POSITION
#define STS_SERVO_STATUS_READ_LEN ((uint8_t)(STS_SERVO_ADDR_CURRENT_CURRENT - STS_SERVO_ADDR_CURRENT_POSITION + 2U))
#define STS_SERVO_LOAD_VALUE_MASK (0x03FFU)

__attribute__((weak)) uint32_t sts_servo_platform_get_tick_ms(void)
{
    return 0U;
}

static int16_t sts_servo_constrain_i16(int16_t value, int16_t min, int16_t max)
{
    return (value > max) ? max : ((value < min) ? min : value);
}

static float sts_servo_constrain_float(float value, float min, float max)
{
    return (value > max) ? max : ((value < min) ? min : value);
}

static sts_servo_t *sts_servo_find_by_id(sts_servo_t *servos, uint8_t servo_count, uint8_t id)
{
    if (servos == 0) {
        return 0;
    }

    for (uint8_t i = 0U; i < servo_count; i++) {
        if (servos[i].id == id) {
            return &servos[i];
        }
    }

    return 0;
}

static uint16_t sts_servo_abs_position_error(const sts_servo_t *servo)
{
    int16_t error;

    if (servo == 0) {
        return 0U;
    }

    error = (int16_t)(servo->target_position - servo->current_position);
    return (error < 0) ? (uint16_t)(-error) : (uint16_t)error;
}

static void sts_servo_update_fault_flags(sts_servo_t *servo)
{
    uint32_t faults = STS_SERVO_FAULT_NONE;
    uint16_t load_value;

    if (servo == 0) {
        return;
    }

    if ((servo->current_temperature != 0U) &&
        (servo->current_temperature > servo->max_temperature)) {
        faults |= STS_SERVO_FAULT_OVER_TEMP;
    }
    if ((servo->current_voltage != 0U) &&
        (servo->current_voltage < servo->min_voltage)) {
        faults |= STS_SERVO_FAULT_UNDER_VOLTAGE;
    }
    if ((servo->current_voltage != 0U) &&
        (servo->current_voltage > servo->max_voltage)) {
        faults |= STS_SERVO_FAULT_OVER_VOLTAGE;
    }

    load_value = (uint16_t)(servo->current_load & STS_SERVO_LOAD_VALUE_MASK);
    if ((servo->max_load != 0U) && (load_value > servo->max_load)) {
        faults |= STS_SERVO_FAULT_OVER_LOAD;
    }
    if ((servo->max_current != 0U) &&
        (servo->current_current != 0U) &&
        (servo->current_current > servo->max_current)) {
        faults |= STS_SERVO_FAULT_OVER_CURRENT;
    }
    if ((servo->max_position_error != 0U) &&
        (sts_servo_abs_position_error(servo) > servo->max_position_error)) {
        faults |= STS_SERVO_FAULT_POSITION_ERROR;
    }
    if (servo->last_status == STS_SERVO_ERR_TIMEOUT) {
        faults |= STS_SERVO_FAULT_BUS_TIMEOUT;
    }
    if ((servo->status_flags != 0U) || (servo->last_status == STS_SERVO_ERR_STATUS)) {
        faults |= STS_SERVO_FAULT_STATUS_ERROR;
    }

    servo->fault_flags = faults;
}

static uint8_t sts_servo_should_disable_torque(const sts_servo_t *servo)
{
    if ((servo == 0) || (servo->protection_enabled == 0U)) {
        return 0U;
    }

    return ((servo->fault_flags & STS_SERVO_PROTECT_DISABLE_TORQUE_FAULTS) != 0UL) ? 1U : 0U;
}

static uint8_t sts_servo_packet_checksum(uint8_t id,
                                         uint8_t length,
                                         uint8_t instruction_or_error,
                                         const uint8_t *params,
                                         uint8_t param_len)
{
    uint16_t sum = (uint16_t)id + length + instruction_or_error;

    for (uint8_t i = 0U; i < param_len; i++) {
        sum += params[i];
    }

    return (uint8_t)(~((uint8_t)sum));
}

static void sts_servo_parser_reset(sts_servo_bus_t *bus)
{
    bus->parser_state = STS_SERVO_PARSER_WAIT_HEADER_1;
    bus->parser_param_index = 0U;
    bus->parser_sum = 0U;
    bus->response.id = 0U;
    bus->response.length = 0U;
    bus->response.error = 0U;
    bus->response.param_len = 0U;
    bus->response.checksum = 0U;
}

static uint8_t sts_servo_queue_push(sts_servo_bus_t *bus, const sts_servo_command_t *cmd)
{
    if ((bus == 0) || (cmd == 0) || (bus->queue_count >= STS_SERVO_CMD_QUEUE_SIZE)) {
        return 0U;
    }

    bus->queue[bus->queue_head] = *cmd;
    bus->queue_head = (uint8_t)((bus->queue_head + 1U) % STS_SERVO_CMD_QUEUE_SIZE);
    bus->queue_count++;
    return 1U;
}

static uint8_t sts_servo_queue_pop(sts_servo_bus_t *bus, sts_servo_command_t *cmd)
{
    if ((bus == 0) || (cmd == 0) || (bus->queue_count == 0U)) {
        return 0U;
    }

    *cmd = bus->queue[bus->queue_tail];
    bus->queue_tail = (uint8_t)((bus->queue_tail + 1U) % STS_SERVO_CMD_QUEUE_SIZE);
    bus->queue_count--;
    return 1U;
}

static uint8_t sts_servo_response_push(sts_servo_bus_t *bus, const sts_servo_response_t *response)
{
    if ((bus == 0) || (response == 0) || (bus->response_count >= STS_SERVO_RSP_QUEUE_SIZE)) {
        return 0U;
    }

    bus->response_queue[bus->response_head] = *response;
    bus->response_head = (uint8_t)((bus->response_head + 1U) % STS_SERVO_RSP_QUEUE_SIZE);
    bus->response_count++;
    return 1U;
}

sts_servo_status_t sts_servo_pop_response(sts_servo_bus_t *bus, sts_servo_response_t *response)
{
    if ((bus == 0) || (response == 0)) {
        return STS_SERVO_ERR_NULL;
    }
    if (bus->response_count == 0U) {
        return STS_SERVO_PENDING;
    }

    *response = bus->response_queue[bus->response_tail];
    bus->response_tail = (uint8_t)((bus->response_tail + 1U) % STS_SERVO_RSP_QUEUE_SIZE);
    bus->response_count--;
    return STS_SERVO_OK;
}

static sts_servo_status_t sts_servo_encode_command(sts_servo_bus_t *bus,
                                                   const sts_servo_command_t *cmd,
                                                   uint16_t *packet_len)
{
    uint8_t length;

    if ((bus == 0) || (cmd == 0) || (packet_len == 0)) {
        return STS_SERVO_ERR_NULL;
    }

    length = (uint8_t)(cmd->param_len + 2U);
    *packet_len = (uint16_t)cmd->param_len + STS_SERVO_MIN_PACKET_LEN;
    if (*packet_len > STS_SERVO_TX_BUF_SIZE) {
        return STS_SERVO_ERR_OVERFLOW;
    }

    bus->tx_buf[0] = STS_SERVO_HEADER_1;
    bus->tx_buf[1] = STS_SERVO_HEADER_2;
    bus->tx_buf[2] = cmd->id;
    bus->tx_buf[3] = length;
    bus->tx_buf[4] = cmd->instruction;

    for (uint8_t i = 0U; i < cmd->param_len; i++) {
        bus->tx_buf[5U + i] = cmd->params[i];
    }

    bus->tx_buf[5U + cmd->param_len] =
        sts_servo_packet_checksum(cmd->id, length, cmd->instruction, cmd->params, cmd->param_len);

    return STS_SERVO_OK;
}
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

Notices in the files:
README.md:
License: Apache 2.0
